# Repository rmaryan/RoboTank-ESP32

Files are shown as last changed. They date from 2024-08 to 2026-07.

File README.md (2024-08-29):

# RoboTank-ESP32

<table>
<tr>
    <td><H2>A source code and schematics for the ESP32-based robot with the 6-servos manipulator</H2></td>
<td>
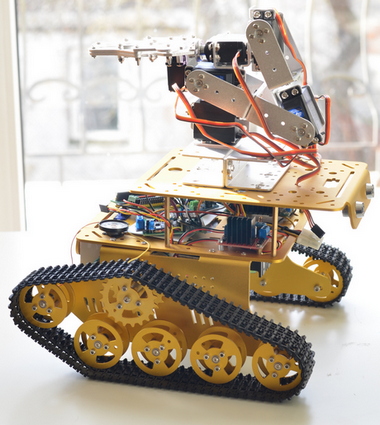
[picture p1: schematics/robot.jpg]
  
</td>
</tr>
</table>

## Contents
  * [Used Components](#used-components)
  * [ESP IDF Requirements](#esp-idf-requirements)
  * [Schematics](#schematics)
  * [Remote Control](#remote-control)
  * [Robot's Web Page and OTA](#robot-s-web-page-and-ota)
  * [On-board sounds](#on-board-sounds)
  * [3D Models](#3d-models)

## Used Components

  * [ESP32 DevBoard](https://www.banggood.com/ESP32-Development-Board-WiFibluetooth-Ultra-Low-Power-Consumption-Dual-Cores-ESP-32-ESP-32S-Board-p-1109512.html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)
  * [Geekcreit DT300 WIFI Double Decker Tank Chassis](https://www.banggood.com/DT300-WIFI-Double-Layer-Decker-Tracked-Model-Robot-Tank-DIY-Kit-Compatible-With-Arduino-UNO-R3-p-1079947.html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)
  * [L298N Dual H Bridge Motor Driver](https://www.banggood.com/Wholesale-L298N-Dual-H-Bridge-Stepper-Motor-Driver-Board-p-42826.html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)
  * [PCA9685 16-Channel 12-bit PWM Extender I2C](https://www.banggood.com/PCA9685-16-Channel-12-bit-PWM-Servo-Motor-Driver-I2C-Module-p-1170343.html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)
  * [6-DOF Robotic Arm](https://www.banggood.com/ROT2U-6DOF-Silver-Aluminium-Robot-Arm-Clamp-Claw-Mount-Kit-With-Servos-p-1118027.html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) - please note, we had to replace two of the original MG996R servos with stronger ones (see below)
  * [SPT Servo SPT5535LV-320 35KG 320°](https://www.banggood.com/SPT-Servo-SPT5535LV-320-35KG-Large-Torque-Metal-Gear-Digital-Servo-For-RC-Robot-RC-Robot-Arm-p-1577513.html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)
  * [SPT Servo SPT5525LV-320 25KG 320°](https://www.banggood.com/SPT-Servo-SPT5525LV-320-25KG-Digital-Servo-320-Metal-Gear-Large-Torque-Servo-For-RC-Robot-p-1383203.html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)
  * [Ultrasonic distance sensor HC-SR04 with the servo-mounting cradle](https://www.banggood.com/Wholesale-Geekcreit-Ultrasonic-Module-HC-SR04-Distance-Measuring-Ranging-Transducer-Sensor-DC-5V-2-450cm-p-40313.html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) 
  * [TowerPro SG90 Mini Gear Micro Servo 9g](http://www.banggood.com/TowerPro-SG90-Mini-Gear-Micro-Servo-9g-For-RC-Airplane-Helicopter-p-1009914.html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)
  * [Infrared Obstacle Detectors](https://www.banggood.com/5Pcs-Infrared-Obstacle-Avoidance-Sensor-Smart-Car-Robot-p-951032.html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) - 4x
  * [LED Lights caps](https://www.banggood.com/3mm5mm8mm10mm-Lightcup-5Pcs-For-RC-Car-LED-Lights-p-930752.html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)
  * [WS2812B SMD LED boards](https://www.banggood.com/10Pcs-DC-5V-3MM-x-10MM-WS2812B-SMD-LED-Board-Built-in-IC-WS2812-p-958213.html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)
  * [Logical Level Converter TXB0104 4-Bit](https://www.banggood.com/CJMCU-401-TXB0104-4-Bit-Bidirectional-Voltage-Level-Translator-Auto-Direction-Sensing-ESD-Protection-p-1149178.html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) - 2x
  * [Sound module WTV020-SD with Mini SD Card](https://www.banggood.com/WTV020-WTV020-SD-Mini-SD-Card-MP3-Sound-Module-For-PIC-WTV020-SD-16P-p-1540568.html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)
  * [LM386 Audio Amplifier](https://www.banggood.com/LM386-Module-20-Times-Gain-Audio-Amplifier-Module-With-Adjustable-Resistance-p-1111643.html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)
  * [Flysky 2.4G 6CH FS-iA6B Receiver](https://www.banggood.com/Flysky-2_4G-6CH-FS-iA6B-Receiver-PPM-Output-With-iBus-Port-p-978603.html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) - can be used with a RC transmitter like [FlySky FS-i6 2.4G 6CH](https://www.banggood.com/FlySky-FS-i6-2_4G-6CH-AFHDS-RC-Radion-Transmitter-With-FS-iA6B-Receiver-for-RC-FPV-Drone-p-983537.html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)
  * [DC-DC Step Down Power Converter](https://www.banggood.com/DC-DC-CC-CV-Buck-Converter-Board-Step-Down-Power-Supply-Module-7-32V-to-0_8-28V-12A-p-1245047.html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)
  * [Battery Management System 2S 7.4V 8A Peak Current 15A for 18650 Lithium Battery](https://www.banggood.com/2S-7_4V-8A-Peak-Current-15A-18650-Lithium-Battery-Protection-Board-With-Over-Charge-Protection-p-1259709.html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) - 2x
  * [18650 Li-Ion Elements](https://www.banggood.com/4Pcs-INR18650-30Q-3000mAh-20A-Discharge-Current-18650-Power-Battery-Unprotected-Button-Top-18650-Battery-For-Flashlights-E-Cig-Tools-p-10671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) - 4x, make sure you've got at least 20A rated max output. Arm servos can be very power-hungry.
  * [Geekcreit Green 0.28 Inch 2.6V-30V Mini Digital Voltmeter - 2x](https://www.banggood.com/5Pcs-Geekcreit-Green-0_28-Inch-2_6V-30V-Mini-Digital-Volt-Meter-Voltage-Tester-Voltmeter-p-980041.html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)

## ESP IDF Requirements

This project relies on the features introduced in ESP IDF version 4.1. Make sure you use at least this version.

## Schematics
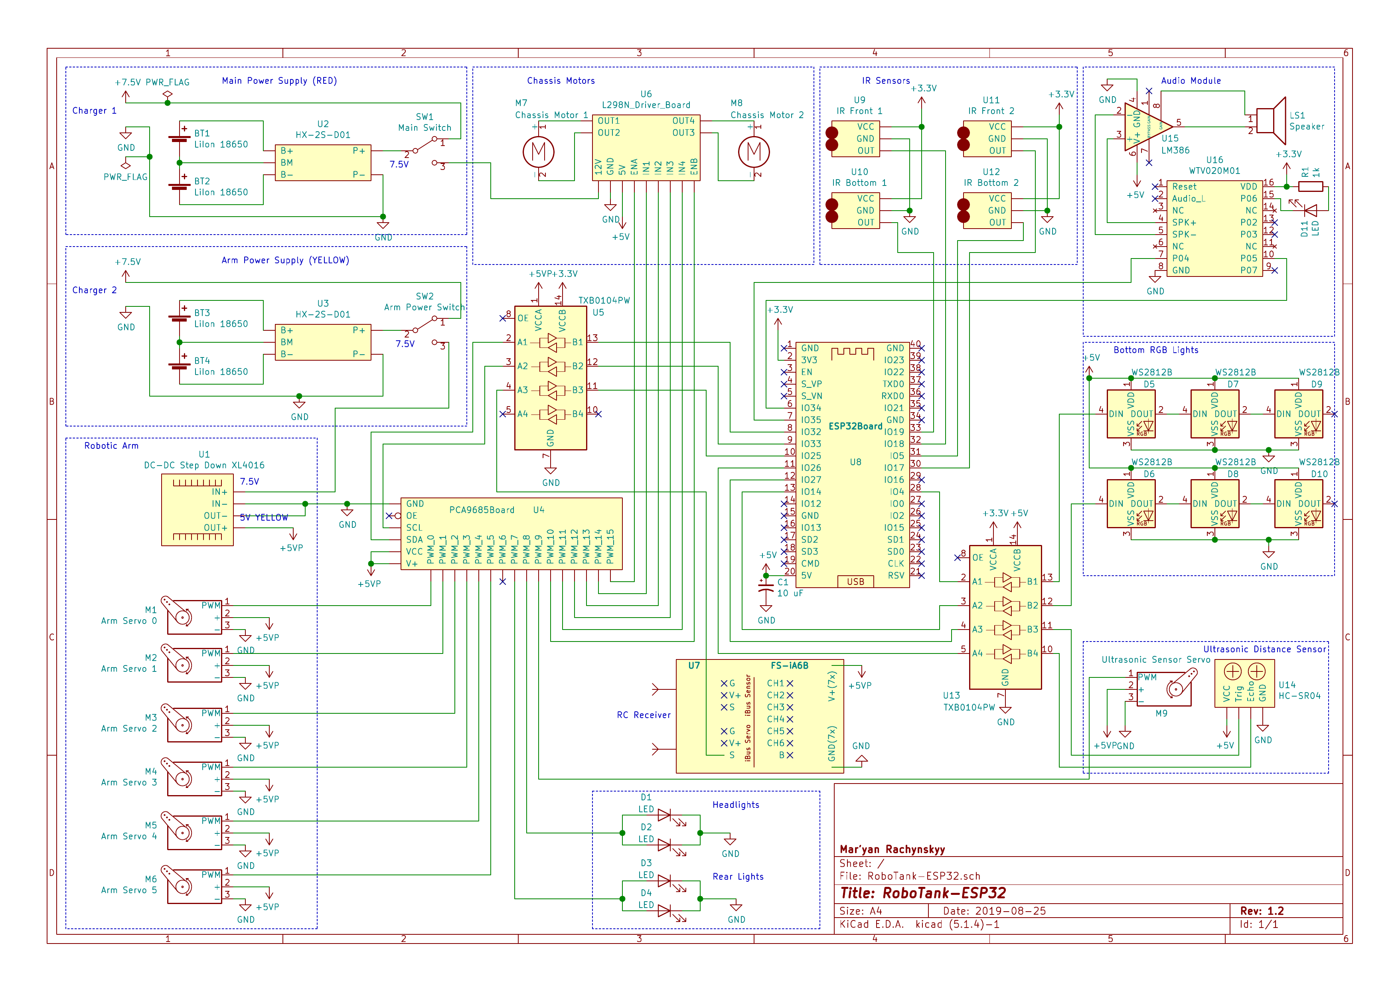
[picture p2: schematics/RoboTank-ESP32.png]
Schematics


## Remote Control

We use Flysky FS-i6 a 2.4GHz 6-channel transmitter which is absolutely sufficient for our case. 

The functionality was expanded with the alternative firmware version from this source: [https://github.com/qba667/FlySkyI6](https://github.com/qba667/FlySkyI6). The number of channels increased to 14 (we use 10 though). Also there are numerous functionality and ui improvements.

To access all channels at the robot's side, RC receiver is connected using iBus digital interface. Anyway it is more natural for the microcontroller-based projects, though require some processing power to read the messages stream and decode RC switches and gimbals positions.

### Flysky FS-i6 Layout

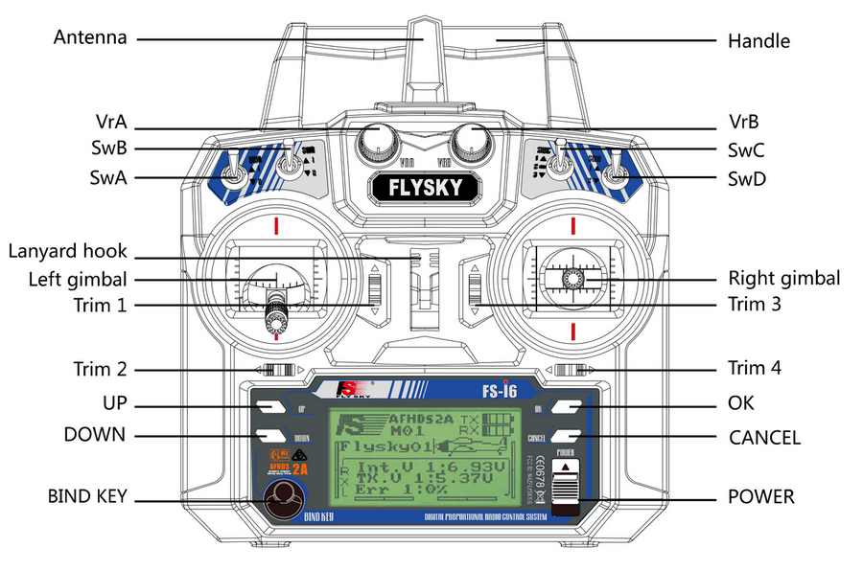
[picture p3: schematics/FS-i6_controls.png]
Flysky FS-i6 Controls


### RC Channels Mapping and Flow Chart

| RC Transmitter Switch | Channel # | Function |
| :--- | :---: | :--- |
| Left Gimbal | 3 and 4 | Controls the arm servos (depends on SWC position) |
| Right Gimbal | 1 and 2 | Controls the chassis motors |
| SWA | 5 | **Remote control activation** <br/>UP - Remote Control is active<br/>DOWN - Remote Control is inactive<br/>*After power on or reconnect, switch SWA down then up to activate RC. For the safety reasons all remote commands will be ignored until such initial activation sequence take place.* |
| SWB | 6 | **AI mode activation**<br/>UP - manual control mode<br/>DOWN - AI control mode (RC should still be activated first) |
| VRA | 7 | *nothing at the moment* |
| VRB | 8 | *nothing at the moment* |
| SWC | 9 | **Arm sevos pair selection**<br/> Selects which pair of servos are going to be controlled by the left gimbal (1=>top, 2=>middle, 3=>bottom) |
| SWD | 10 | **Lights Toggle**<br/>UP - all lights ON<br/>DOWN - all lights OFF |

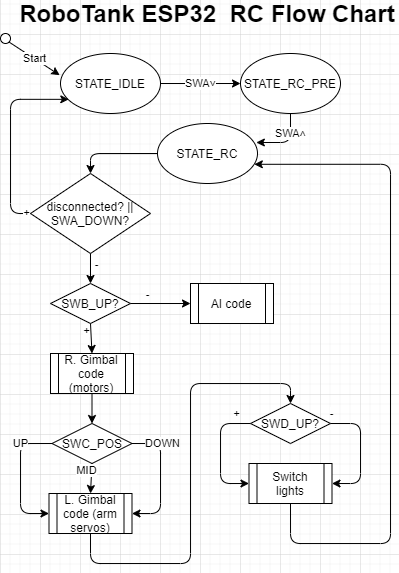
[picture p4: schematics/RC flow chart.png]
RC Flow Chart


## Robot's Web Page and OTA

Right after booting, the robot tries to connect to the local WiFi network. Connection parameters can be specified in "OTA WiFi Configuration" in make menuconfig.  

Having a connection started, robot launches own Web Server. You can find the IP address of the robot in your WiFi router settings pages (making it static can be a good idea). 

Direct your web browser to the robot's IP address and a home page will be shown. You can upload new firmware updates there (so you don't need to connect your robot with the USB wire any more). Also you can see the log messges output right on the web page (this feature will work if LOG_USE_WEB_FRONTEND is defined in RoboTank-ESP32.cpp). 

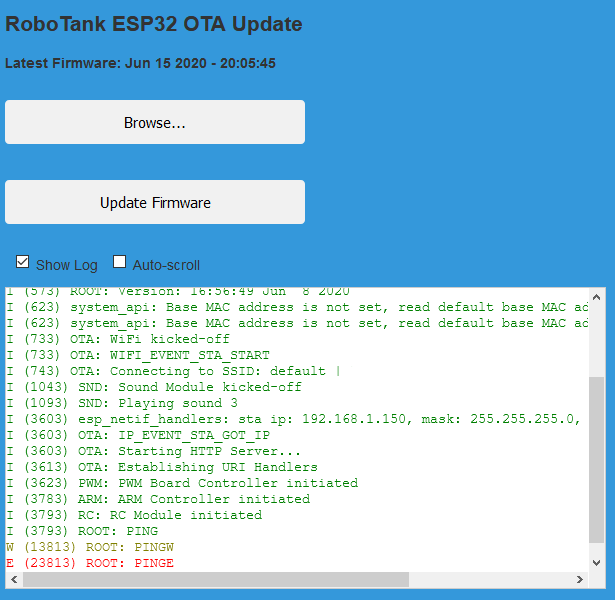
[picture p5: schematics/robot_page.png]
Schematics


## On-board sounds

Place the files from sdcard folder to the root of the sound module SD card.

Tracks are the following:
  * 0000.AD4 - Thinking
  * 0001.AD4 - Working
  * 0002.AD4 - Talking
  * 0003.AD4 - Hello
  * 0004.AD4 - Scared
  * 0005.AD4 - Be careful
  * 0006.AD4 - Vivaldi - Winter

Files were converted from the original MP3's as described here: https://www.buildcircuit.com/how-to-convert-mp3-and-wav-files-to-ad4-format-wtv020sd-tutorial/

## 3D Models

Some of the parts were 3D-printed. Corresponding FreeCAD and STL files are provided in the [schematics/3D Models](schematics/3D%20Models) folder.

  * RC Antenna cradle
  * IR distance sensors consoles
  * Backside voltmeters cradles
  
# Liked some of my work?

<a href="https://www.buymeacoffee.com/maryanR" target="_blank">Buy Me A Coffee</a>

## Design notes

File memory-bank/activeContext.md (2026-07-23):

# Active Context: RoboTank-ESP32

## Current Work Focus
Initial memory bank creation for the project. The codebase is a well-structured ESP32 firmware application built with PlatformIO and ESP-IDF framework, managing multiple robotic subsystems concurrently via FreeRTOS tasks.

## Recent Changes
No recent changes documented yet - this is the first session documenting this repository (commit: `cdf3718`).

## Next Steps
- Review all source files in detail to understand current implementation state
- Validate RC controller PWM signal processing logic

## Active Decisions and Considerations
- Project uses `include/` for headers and `src/` for implementations consistently
- Pin configuration is centralized in `pin_mapping.h` header - reference this file before any hardware-related changes
- FreeRTOS tasks are used extensively (AITask, RCControllerTask) with separate task files
- PlatformIO platform (`platformio.ini`) drives the build system rather than raw ESP-IDF Makefiles (beware - project uses pioarduino fork and VS Code plugin)

## Important Patterns and Preferences
- Each subsystem has both a header (.h) implementation (.cpp) pair in `include/` and `src/` respectively
- Utility functions are centralized in `RoboTankUtils.cpp`
- Per-module logging via `rtank_esp_log.h` for consistent log output

## Learnings and Project Insights
- The project includes schematics for mechanical design (`3D Models/`) and circuit diagrams (`flow chart.drawio`, `.png`) - useful reference before hardware-related modifications
- SD card directory contains `.AD4` sound files (WTV020SD16P format) for playback via SoundModuleController at track IDs 1-512

<!-- MEMORY BANK INITIALIZED -->

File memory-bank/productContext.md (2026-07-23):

# Product Context: RoboTank-ESP32

## Purpose
RoboTank-ESP32 serves as a fully programmable, WiFi-enabled robotic tank platform designed for educational purposes and hobbyist experimentation with robotics, embedded systems, and IoT concepts.

## Problems Solved
- **Complex hardware integration**: Provides pre-built, tested drivers for common robot components (motors, servos, sensors) so users can focus on application logic
- **Wireless control convenience**: Enables RC-style control combined with WiFi-based OTA updates and web interface access
- **Development workflow simplification**: PlatformIO + ESP-IDF setup eliminates manual SDK configuration

## How It Works
The system operates through multiple FreeRTOS tasks running on the ESP32:
1. **RCControllerTask** reads PWM signals from an FS-i6 transmitter receiver and maps channels to robot commands
2. **AITask** handles autonomous/remote logic processing based on RC input and sensor data
3. **Component controllers** (ArmController, MotorsL298NDriver, LEDsMT, SensorsController, etc.) manage individual hardware subsystems concurrently
4. **BufLogger** handles logging: intercepts ESP-IDF log output into ring buffer → serves via HTTP to web page + serial port
5. **OTAManager** handles firmware updates without physical connection

## User Experience Goals
- Plug-and-play setup with PlatformIO upload via USB or OTA
- Immediate feedback through LEDs, sounds, and motor response
- Intuitive RC control mapping for both manual operation and programmed sequences
- Reliable sensor readings and actuator responses in real-time

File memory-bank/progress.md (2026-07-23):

# Progress: RoboTank-ESP32

## What Works
Based on existing codebase analysis, the following subsystems appear implemented:
- RC Controller PWM signal decoding (FS-i6 protocol) for channel reading and command mapping
- Motor control via L298N driver interface with directional/speed commands from RC input or AI task logic
- Servo-based robotic arm position management through ArmController
- RMT-driven RGB LED strip effects managed by LEDsMT controller
- Sensor data aggregation pipeline in SensorsController for real-time state monitoring and feedback to tasks
- Audio playback system integration via SoundModuleController (likely WAV/MP3 module communication)
- OTA firmware update capability with OTAManager handling WiFi-based upload workflow without serial reconnection
- Pin mapping validation against physical build wiring (`include/pin_mapping.h`) verified with actual hardware connections shown in schematics
- RC controller signal processing accuracy for FS-i6 receiver (PPM protocol) tested on real hardware successfully
- Sensor calibration values and threshold configurations tuned per installed sensors, all thresholds working correctly

## What's Left to Build / Improve
### General
- Power management integration between LightsController sleep/wake cycle, OTAManager power considerations during OTA window, and overall current draw optimization
- Web interface content in `src/webcontent/` directory - endpoint handlers for WiFi AP/client mode operation not yet visible from file structure alone

### AI Mode Implementation (TODO)
- `AITask::processTickAI()` contains only a `ArmController::parkArm()` call — the method body is marked as TODO
  - **Option A**: Implement basic autonomous mode (obstacle avoidance + patrolling behavior)
  - **Option B**: Rename to `manualMode()` or `rcControlTick()` if AI autonomy is out of scope
- Current state at `src/AITask.cpp`: empty stub with single park call as placeholder

### Hard-coded Timeouts and Magic Numbers
- `OTAManager.cpp` line ~290: index calculation `(body_start_p - ota_buff)` without explicit intermediate variables — hard to read and debug
- `SensorsController.cpp` line ~145: `rmt_receive()` + `xQueueReceive()` in `while(1)` loop with 1000ms timeout
  - **Risk**: If US sensor is not connected or unstable, this blocks the task for 1+ second
  - **Recommendation**: Use non-blocking RMT callbacks or shorter timeouts with periodic polling

### Insufficient Error Handling on init() Calls
- Multiple modules call `init()` without checking ESP-IDF return codes (`esp_err_t`):
  - `MotorL298NDriver::init()` — what if I2C bus is unavailable?
  - `ArmController::init()` — was PCA9685 initialized successfully?
  - **Recommendation**: Add error checks on all ESP-IDF driver initialization calls; log failures and return status codes

### Pin Configuration Refactoring
- `include/pin_mapping.h` contains all hardware connections as hard-coded macros
- **Recommendation**: Move configurable pins to:
  - `sdkconfig` or NVS for pins that may vary between project builds
  - A `pin_config_t` struct with runtime validation

### OTA Safety Improvements
- Current code lacks firmware integrity verification:
  - No CRC/hash check of uploaded firmware — corrupted file can brick the device
  - No `content_length` validation before writing
- **Recommendation**: Add HMAC or XOR checksum verification before `esp_ota_end()`

### Persistent Storage for Configuration Data (NVS)
- WiFi credentials are stored in ESP-IDF WIFI_STORAGE (Flash), but the following are NOT persisted:
  - Servo calibration data (`SERVO_CALIBRATION_MODE`)
  - Last device state / events for debugging purposes
- **Recommendation**: Use NVS to store calibration tables, last known state, and error logs

## Current Status
**Version**: Early-stage firmware (commit `cdf3718`)
**State**: Core modules implemented, integration testing needed per subsystem combination
**Branch**: main (default)

## Known Issues
Not documented in codebase history yet. To be updated as bugs are discovered during hardware testing and field trials.

## Evolution of Project Decisions
Initial memory bank created at commit `cdf3718`. Key architectural decisions to revisit as hardware iterations occur:
- L298N vs MOSFET motor drivers (power efficiency tradeoffs)
- RMT peripheral for LEDs vs DMA SPI (pixel timing precision requirements depend on LED chip type WS2812B etc.)
- FS-i6 RC receiver protocol selection determining `RCControllerTask` parsing approach

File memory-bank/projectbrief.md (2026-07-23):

# Project Brief: RoboTank-ESP32

## Overview
RoboTank-ESP32 is an ESP32-based robotic tank project featuring advanced control systems including arm manipulation, sensor integration, wireless communication, and SD card logging.

## Core Requirements
- Remote control via RC transmitter (FS-i6) with PWM signal decoding
- Robotic arm control with multiple degrees of freedom
- Real-time sensor monitoring and feedback
- LED strip effects for visual indication
- Audio playback module for alerts/announcements
- Over-the-Air (OTA) firmware updates
- Web-based interface capabilities for triggering OTA and reviewing logs

## Key Features
- Multi-module architecture with separated concerns
- Non-blocking task management via FreeRTOS tasks
- Power-efficient design with sleep/wake support
- Modular component drivers for reusable hardware abstraction

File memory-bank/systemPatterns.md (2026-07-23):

# System Patterns: RoboTank-ESP32

## Architecture Overview
The system follows a **Modular Task-Based** architecture where each major subsystem operates as an independent module with clear separation of concerns. The main entry point is `src/Robo-tank-ESP32.cpp` which initializes all components and starts FreeRTOS tasks.

## Key Technical Decisions

### FreeRTOS Task Model
- Multiple concurrent tasks communicate via queues, semaphores, or shared state
- **AITask.h/cpp** - Central AI/logic coordination task handling high-level decisions
- **RCControllerTask.h/cpp** - Dedicated RC signal processing task running independently

### Hardware Abstraction Pattern
Each peripheral has its own controller class:
- `ArmController` - Servo-based robotic arm manipulation
- `MotorL298NDriver` - DC motor control via L298N H-bridge module
- `LEDRMT` - RGB LED strip driver using RMT peripheral
- `LightsController` - Tank lighting system management
- `SensorsController` - Multi-sensor data aggregation
- `SoundModuleController` - WTV020SD16P sound board controller for .AD4 track playback (files stored on SD card)
- `PWMBoardController` - PWM signal generation/board-level output

### Logging Architecture
- **BufLogger** - Intercepts esp-log framework via ring buffer, collects messages and redirects them to alternative receivers (serial port + web page). On overflow, oldest messages are dropped. Does NOT write to SD card.
- **rtank_esp_log.h/cpp** - Module-specific log wrapper using ESP-IDF log facility

## Component Relationships
```
                     +------------------+
                     |   main (Entry)   |
                     +--------+---------+
                              |
             +---------------+---------------+
             |               |               |
      +------v-----+  +------v------+ +----v-------+
      | AITask     |  | RCController| | OTAManager |
      +------------+  +-------------+ +------------+
             |               
     +-------v---------------+--------+       
     |         Shared State / API      |     
     +-------------------------------+        
                             |                
            +--------------+--+--+-----------+ 
            |              |       |          |      
   +------v------+ +-----v----+ +-v---------+-+----------+
   |ArmController|  | Motors   ||Sensors    ||SoundModule|
   +-------------+  +----------+ +----------++-+---------+
            |                             |           |     
   +-------v--------+             +------v------+     v      
   |PWMBoardCtrl/Li|          +-WebServer----->|  .AD4 Files
   +----------------+          | (BufLogger)    |     on SD    
   +------------------+        +----------------+ 
```

## Sound System Architecture
- **SoundModuleController** manages WTV020SD16P sound module via parallel port interface
- Sounds stored as `.AD4` files on SD card (track IDs 1-512)
- Triggered by other modules during specific events (e.g., AI decisions, sensor alerts)

## Design Patterns in Use
- **Controller Pattern**: Each hardware subsystem has a dedicated controller class
- **Observer-like communication**: Shared state updates trigger downstream reactions
- **Singleton-style modules**: Controller instances typically created once at initialization with global/static access patterns

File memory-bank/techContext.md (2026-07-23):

# Tech Context: RoboTank-ESP32

## Technologies Used
- **Microcontroller**: ESP32 (dual-core Xtensa LX6)
- **Framework**: ESP-IDF (Espressif IoT Development Framework)
- **Build System**: PlatformIO with CMake (pioarduino fork)
- **RTOS**: FreeRTOS (bundled with ESP-IDF)
- **Language**: C/C++

## Development Environment Setup
- IDE: VS Code with pioarduino extension
- Configuration file: `platformio.ini` in project root
- Upload methods: USB serial or OTA (`OTAManager`)

## Dependencies & Libraries
Dependencies are declared in `platformio.ini`. Key ones likely include:
- ESP-IDF core (WiFi, SPIFFS/LittleFS)
- RMT driver for LED control
- Servo/PWM drivers for arm and motors
- SD/MMC library for card storage
- FS-i6 RC receiver signal decoding (PWM/GCS protocol parsing)

## Technical Constraints
- **Memory**: ESP32 SRAM (~520KB internal), PSRAM if equipped
- **Power**: Battery-powered, requires sleep/wake support (`LightsController` and `OTAManager`) for power management
- **Pin mapping**: Centralized in `include/pin_mapping.h` - all hardware references must align here
- **WiFi antenna**: Internal PCB trace on ESP32-WROOM; RF considerations near antenna area

## Tool Usage Patterns
- PlatformIO CLI (`pio run`, `pio upload`, ` pio device monitor`) for build/deploy/debug cycle - beware of the pioarduino specifics
- CMakeLists.txt in both root and `src/` directories (PlatformIO handles this automatically)

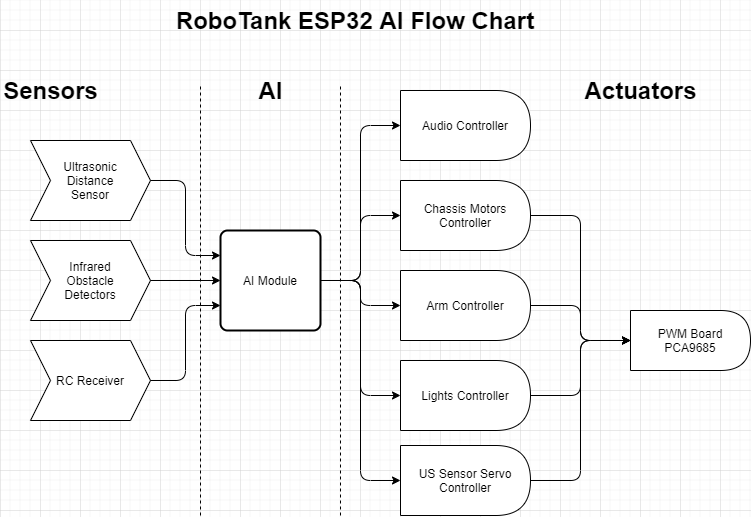
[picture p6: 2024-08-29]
schematics/flow chart.png

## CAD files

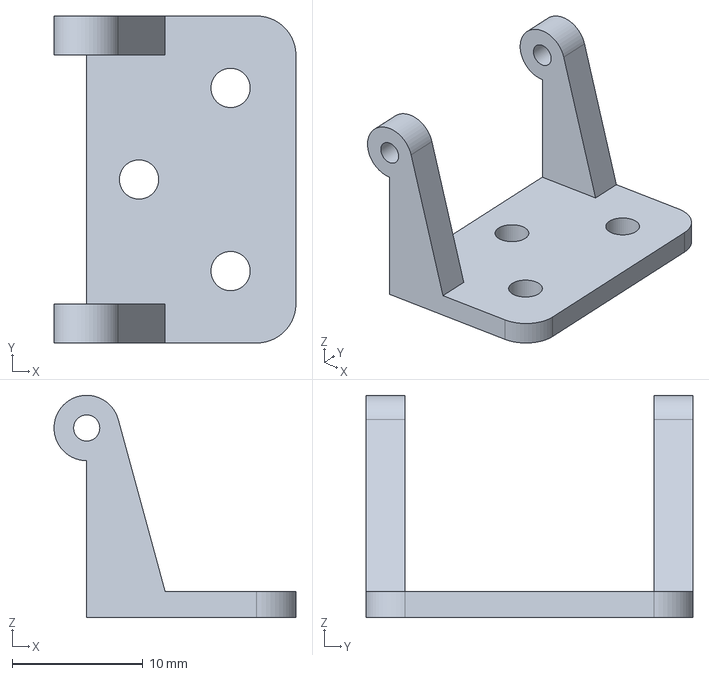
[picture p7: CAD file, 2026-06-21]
schematics/3D Models/FPVCameraHolder.FCStd
18.5 x 25.0 x 17.0 mm

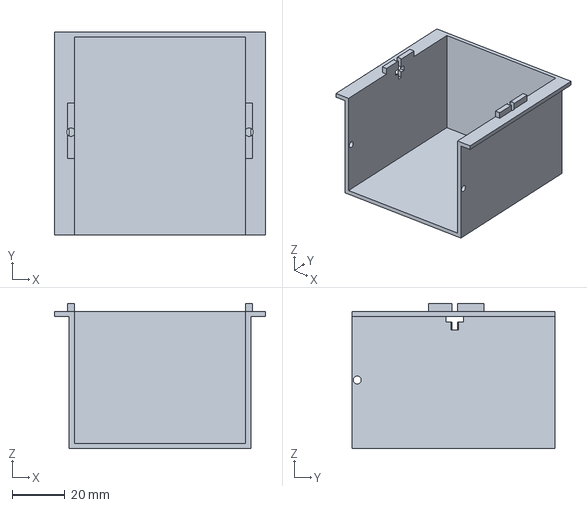
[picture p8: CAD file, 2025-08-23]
schematics/3D Models/BatHolder.FCStd
80.0 x 77.0 x 55.0 mm

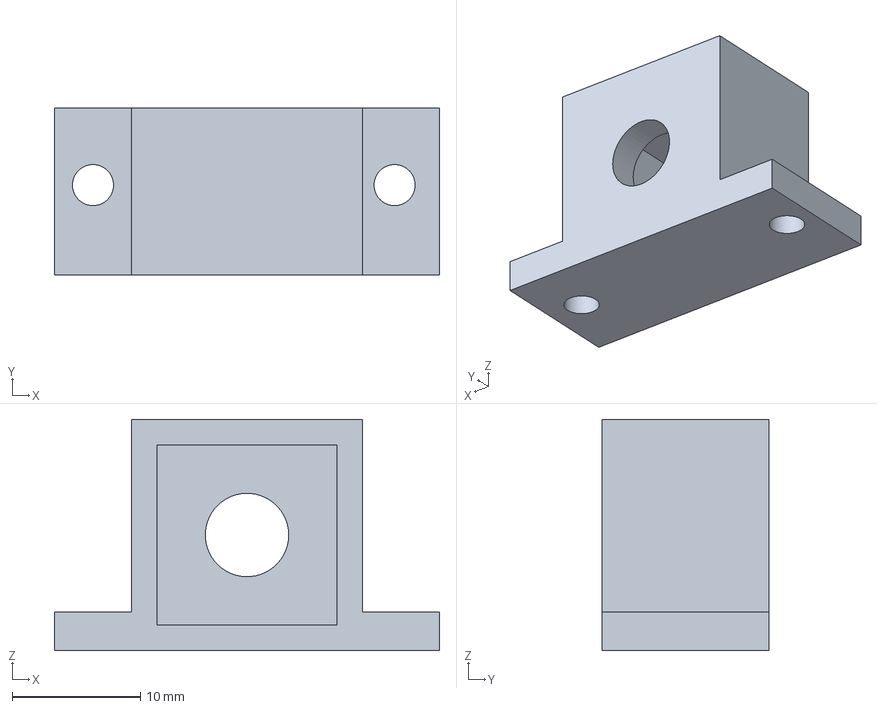
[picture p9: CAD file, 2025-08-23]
schematics/3D Models/SwitchHolder.FCStd
30.0 x 13.0 x 18.0 mm

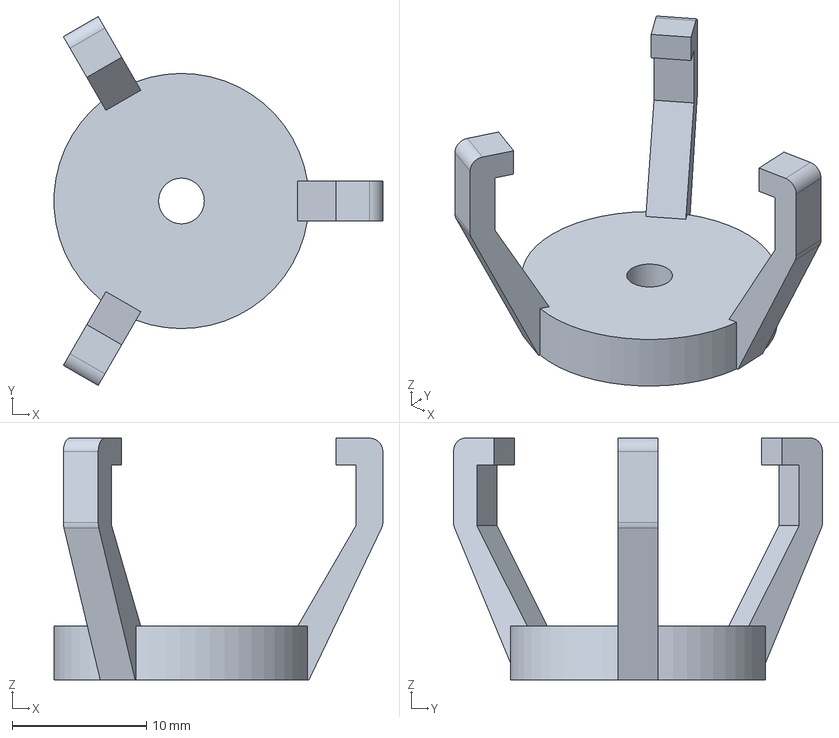
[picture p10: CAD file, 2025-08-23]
schematics/3D Models/BeeperHolder.FCStd
24.5 x 27.5 x 18.0 mm

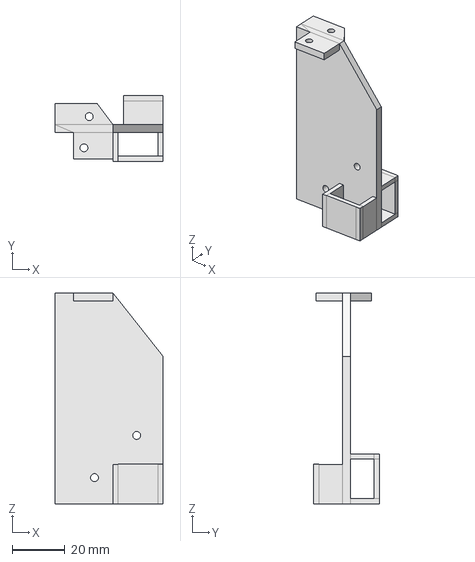
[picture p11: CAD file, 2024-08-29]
schematics/3D Models/sensors_console.FCStd
41.0 x 25.0 x 80.0 mm

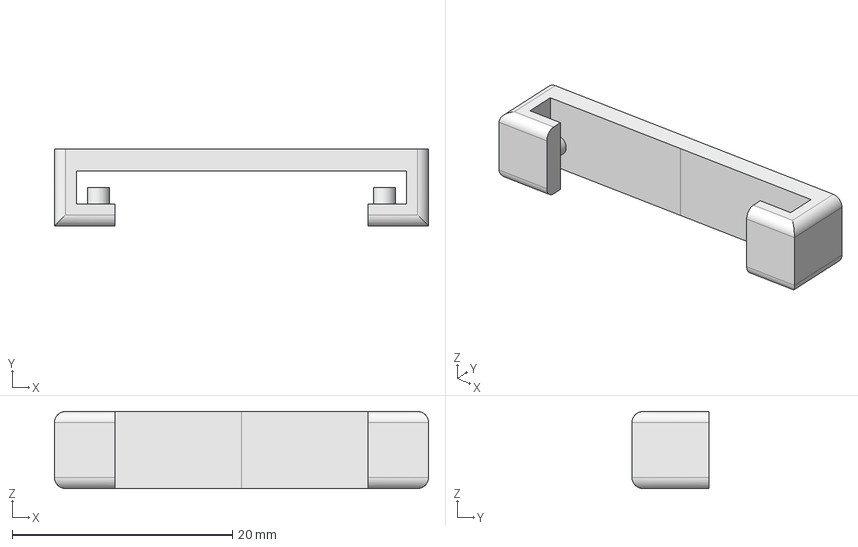
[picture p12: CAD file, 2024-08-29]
schematics/3D Models/voltmeter_cradle.FCStd
34.0 x 7.00 x 7.00 mm

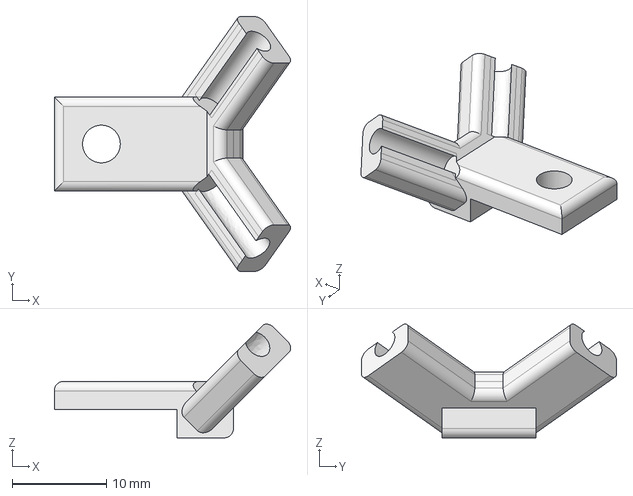
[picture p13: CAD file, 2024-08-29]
schematics/3D Models/antenna_cradle.FCStd
25.1 x 27.0 x 12.1 mm

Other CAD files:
schematics/3D Models/BatHolder.3mf
schematics/3D Models/BeeperHolder.3mf
schematics/3D Models/FPVCameraHolder.3mf
schematics/3D Models/SwitchHolder.3mf
schematics/3D Models/sensors_console.3mf
schematics/3D Models/sensors_console.stl
schematics/3D Models/voltmeter_cradle.stl

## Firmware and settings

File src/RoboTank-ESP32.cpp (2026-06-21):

/*
 *  Tank robot with sensors and manipulators built on ESP32 microcontroller.
 *
 *  THE ENTRY POINT
 *
 *  Minimum ESP-IDF version required: 4.0
 *
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
 */

#include "rtank_esp_log.h"
#include "freertos/FreeRTOS.h"
#include "freertos/task.h"
#include "OTAManager.h"
#include "PWMBoardController.h"
#include "MotorL298NDriver.h"
#include "SoundModuleController.h"
#include "ArmController.h"
#include "LightsController.h"
#include "SensorsController.h"
#include "RCControllerTask.h"
#include "AITask.h"
#include "RoboTankUtils.h"

#ifdef LOG_USE_WEB_FRONTEND
#include "BufLogger.h"
#endif

static const char* LOG_TAG = LOG_TAG_ROOT;

extern "C" {
void app_main();
}

void app_main()
{
	// Initialize the logging subsystem
	// It allows selecting different log levels for each module
	rtank_esp_log_init();

	// Initialize the web front-end logger
#ifdef LOG_USE_WEB_FRONTEND
	BufLogger::init();
#endif

	ESP_LOGI(LOG_TAG, "Starting the launch sequence...");
	ESP_LOGI(LOG_TAG, "Version: %s %s", __TIME__, __DATE__);

	// Initializing the OTA and web server subsystem
	OTAManager::init();

	// Hello Sound!
	SoundModuleController::init();


	// PWM Board
	PWMBoardController::init();

	// Stop all motors
	MotorL298NDriver::init();

	// Arm Controller
	ArmController::init();
	// This is the arm servos calibration hook.
	// If you uncomment SERVO_CALIBRATION_MODE definition in ArmController.h - the main execution thread is highjacked
	// Connect to the robot in serial console and send servo position commands as requested. This way you can define edge
	// and parking positions for the servos.
#ifdef SERVO_CALIBRATION_MODE
	ArmController::servoCalibration();
	// Nothing is executed beyond this step
#endif

	// Lights controller
	LightsController::init();

	// IR and Ultrasonic Sensors
	SensorsController::init();

	//RC Controller
	RCControllerTask::init();

	//Launch of the AI. Wait 1 second for other modules to settle.
	delay_ms(1000);
	AITask::init();

}

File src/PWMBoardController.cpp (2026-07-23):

/*
 * PWMBoardController.cpp
 *
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
 */

#include "PWMBoardController.h"

#include <math.h>

#include "driver/i2c.h"
#include "esp_check.h"
#include "rtank_esp_log.h"
#include "pin_mapping.h"

// Board-specific definitions
#define I2C_CLK_SPEED 100000		  /* I2C clock speed in Hz */
#define PCA9685_I2C_ADDRESS 0x40	  /* Default PCA9685 I2C Slave Address */
#define FREQUENCY_OSCILLATOR 25000000 /* Int. osc. frequency in datasheet */
#define PCA9685_PRESCALE 0xFE		  /* Prescaler for PWM output frequency */
#define PCA9685_MODE1 0x00			  /* Mode Register 1 */
#define MODE1_RESTART 0x80			  /* Restart enabled */
#define MODE1_SLEEP 0x10			  /* Low power mode. Oscillator off */
#define MODE1_AI 0x20				  /* Auto-Increment enabled */
#define PCA9685_PRESCALE_MIN 3		  /* minimum prescale value */
#define PCA9685_PRESCALE_MAX 255	  /* maximum prescale value */
#define ACK_CHECK_EN 0x1			  /* Check for ACK on I2C bus*/
#define PCA9685_LED0_ON_L 0x06		  /* LED0 on tick, low byte*/

// We hardcode 50 Hz - this is what works for the analog servos
#define SERVOFREQ 50

static const char *LOG_TAG = LOG_TAG_PWM;

SemaphoreHandle_t PWMBoardController::xPWMSemaphore;

void PWMBoardController::init()
{
	// set up the I2C interface
	ESP_LOGI(LOG_TAG, "Initializing the PWM Board Controller...");

	i2c_config_t conf = {};
	conf.mode = I2C_MODE_MASTER;
	conf.sda_io_num = PIN_ESP32_PWM_SDA;
	conf.scl_io_num = PIN_ESP32_PWM_SCL;
	conf.sda_pullup_en = GPIO_PULLUP_ENABLE;
	conf.scl_pullup_en = GPIO_PULLUP_ENABLE;

	conf.master.clk_speed = I2C_CLK_SPEED; // 100 kHz
	ESP_ERROR_CHECK(i2c_param_config(I2C_NUM_0, &conf));
	ESP_ERROR_CHECK(i2c_driver_install(I2C_NUM_0, conf.mode, 0, 0, 0));

	// reset the PWM board
	ESP_ERROR_CHECK(sendPWMData(PCA9685_MODE1, MODE1_RESTART));

	// set up the desired PWM frequency
	float prescaleval = ((FREQUENCY_OSCILLATOR / (SERVOFREQ * 4096.0)) + 0.5) - 1;
	if (prescaleval < PCA9685_PRESCALE_MIN)
		prescaleval = PCA9685_PRESCALE_MIN;
	if (prescaleval > PCA9685_PRESCALE_MAX)
		prescaleval = PCA9685_PRESCALE_MAX;
	uint8_t prescale = round(prescaleval);

	uint8_t oldmode = receivePWMData(PCA9685_MODE1);
	uint8_t newmode = (oldmode & ~MODE1_RESTART) | MODE1_SLEEP; // sleep
	ESP_ERROR_CHECK(sendPWMData(PCA9685_MODE1, newmode));		// go to sleep
	ESP_ERROR_CHECK(sendPWMData(PCA9685_PRESCALE, prescale));	// set the prescaler
	ESP_ERROR_CHECK(sendPWMData(PCA9685_MODE1, oldmode));
	vTaskDelay(5 / portTICK_PERIOD_MS);
	ESP_ERROR_CHECK(sendPWMData(PCA9685_MODE1, oldmode | MODE1_RESTART | MODE1_AI));
	vTaskDelay(10 / portTICK_PERIOD_MS);

	// Create the access safeguard mutex
	xPWMSemaphore = xSemaphoreCreateMutex();
	if (xPWMSemaphore == NULL)
	{
		ESP_LOGE(LOG_TAG, "Semaphore creation failed");
	}

	ESP_LOGI(LOG_TAG, "PWM Board Controller initiated");
}

esp_err_t PWMBoardController::sendPWMData(uint8_t addr, uint8_t data)
{
	esp_err_t error_code;
	i2c_cmd_handle_t cmd = i2c_cmd_link_create();
	i2c_master_start(cmd);
	i2c_master_write_byte(cmd, (PCA9685_I2C_ADDRESS << 1) | I2C_MASTER_WRITE, ACK_CHECK_EN);
	i2c_master_write_byte(cmd, addr, ACK_CHECK_EN);
	i2c_master_write_byte(cmd, data, ACK_CHECK_EN); // potentially for the registers should be NACK_VAL
	i2c_master_stop(cmd);
	error_code = i2c_master_cmd_begin(I2C_NUM_0, cmd, 100 / portTICK_PERIOD_MS);
	i2c_cmd_link_delete(cmd);
	return error_code;
}

bool PWMBoardController::setPWM(uint8_t num, uint16_t on, uint16_t off)
{
	if (xSemaphoreTake(xPWMSemaphore, (TickType_t)400) != pdTRUE)
	{
		ESP_LOGE(LOG_TAG, "Semaphore timeout. PWM command was lost.");
		return false;
	}

	i2c_cmd_handle_t cmd = i2c_cmd_link_create();
	if (cmd == NULL)
	{
		xSemaphoreGive(xPWMSemaphore);
		return false;
	}
	esp_err_t ret = ESP_OK;
	uint8_t data[5] = {
		(uint8_t)(PCA9685_LED0_ON_L + 4 * num),
		(uint8_t)(on & 0xFF),
		(uint8_t)((on >> 8) & 0xFF),
		(uint8_t)(off & 0xFF),
		(uint8_t)((off >> 8) & 0xFF)};

	ESP_GOTO_ON_ERROR(i2c_master_start(cmd), err, LOG_TAG, "Failed to set PWM on channel %d: error code 0x%x", num, ret);
	ESP_GOTO_ON_ERROR(i2c_master_write_byte(cmd, (PCA9685_I2C_ADDRESS << 1) | I2C_MASTER_WRITE, ACK_CHECK_EN), err, LOG_TAG, "Failed to set PWM on channel %d: error code 0x%x", num, ret);
	ESP_GOTO_ON_ERROR(i2c_master_write(cmd, data, sizeof(data), ACK_CHECK_EN), err, LOG_TAG, "Failed to set PWM on channel %d: error code 0x%x", num, ret);
	ESP_GOTO_ON_ERROR(i2c_master_stop(cmd), err, LOG_TAG, "Failed to set PWM on channel %d: error code 0x%x", num, ret);
	ESP_GOTO_ON_ERROR(i2c_master_cmd_begin(I2C_NUM_0, cmd, 10 / portTICK_PERIOD_MS), err, LOG_TAG, "Failed to set PWM on channel %d: error code 0x%x", num, ret);

err:
	i2c_cmd_link_delete(cmd);
	xSemaphoreGive(xPWMSemaphore);

	return (ret == ESP_OK);
}
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

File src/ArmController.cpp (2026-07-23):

/*
 * ArmController.cpp
 *
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
 */

#include <stdio.h>
#include <stdlib.h>
#include <math.h>
#include "rtank_esp_log.h"
#include "ArmController.h"
#include "PWMBoardController.h"
#include "RoboTankUtils.h"

const uint8_t ArmController::SERVO_PWM_PORTS[SERVOS_COUNT] = {
		PIN_PWM_ARM_SERVO0,
		PIN_PWM_ARM_SERVO1,
		PIN_PWM_ARM_SERVO2,
		PIN_PWM_ARM_SERVO3,
		PIN_PWM_ARM_SERVO4,
		PIN_PWM_ARM_SERVO5
};

const uint8_t ArmController::SERVO_MIN_DEG[SERVOS_COUNT] = 	 {0,   15,  10,  30,  10,  45};
const uint8_t ArmController::SERVO_MAX_DEG[SERVOS_COUNT] =   {178, 165, 180, 170, 170, 85};
const uint8_t ArmController::SERVO_PARK_DEG[SERVOS_COUNT] =  {85,  20,  10,  50,  90,  71}; // arm parking positions. Set 255 to skip

uint16_t ArmController::servo_current_position[SERVOS_COUNT] = {};
int16_t  ArmController::servo_current_speed[SERVOS_COUNT] = {};
uint16_t ArmController::servo_target_position[SERVOS_COUNT] =  {};
uint8_t ArmController::servo_target_positionDEG[SERVOS_COUNT] =  {};

#define SERVO_TIMER_TASK_NAME "SERVO TIMER"
TimerHandle_t ArmController::xServoUpdateTimerHandle;

static const char* LOG_TAG = LOG_TAG_ARM;

void ArmController::init() {
	// Make sure the arm is initialized in the parked position
	// Be careful about what you have in your SERVO_PARK_DEG
	// or uninitialized arm can damage lots of stuff around the robot
	parkArm();
	for(int8_t i = (SERVOS_COUNT-1); i>=0; i--) {
		servo_current_position[i] = servo_target_position[i];
		PWMBoardController::setPWM(SERVO_PWM_PORTS[i], 0, servo_current_position[i]);
	}

	// start the arm moving timer task
	// we use it to move smoothly all servos of the arm simultaneously
	xServoUpdateTimerHandle = xTimerCreate(
			SERVO_TIMER_TASK_NAME,
			pdMS_TO_TICKS(SERVO_STEP_DURATION), /* period/time */
			pdTRUE, /* auto reload */
			(void*)0, /* timer ID */
			servoTimerCallback); /* callback */

	if (xServoUpdateTimerHandle!=NULL) {
		if(xTimerStart(xServoUpdateTimerHandle, 0) == pdPASS ) {
			ESP_LOGI(LOG_TAG, "ARM Controller initiated");
		} else {
			ESP_LOGE(LOG_TAG, "ARM Controller Timer start failed");
		}
	} else {
		ESP_LOGE(LOG_TAG, "ARM Controller Timer creation failed");
	}
}

void ArmController::turnServo(uint8_t servoID, int16_t turningAngleDEG) {	
	if((servoID < SERVOS_COUNT) && (turningAngleDEG != 0)) {
		ESP_LOGI(LOG_TAG, "Turning servo %d by %d degrees", servoID, turningAngleDEG);
		int16_t desiredPositionDEG = servo_target_positionDEG[servoID] + turningAngleDEG;
		if(desiredPositionDEG< SERVO_MIN_DEG[servoID])
			desiredPositionDEG = SERVO_MIN_DEG[servoID];
		else
			if(desiredPositionDEG > SERVO_MAX_DEG[servoID])
				desiredPositionDEG = SERVO_MAX_DEG[servoID];

		setServo(servoID, desiredPositionDEG);
	}
}

void ArmController::parkArm() {
	for(int8_t i = (SERVOS_COUNT-1); i>=0; i--) {
		if (SERVO_PARK_DEG[i] != 255) {
            setServo(i, SERVO_PARK_DEG[i]);
        }
	}
}

void ArmController::setServo(uint8_t servoID, uint8_t servoPositionDEG) {
	// Check the parameters validity not to harm innocent PWM lines
	if(servoID < SERVOS_COUNT) {
		if((servoPositionDEG>= SERVO_MIN_DEG[servoID]) &&
				(servoPositionDEG<= SERVO_MAX_DEG[servoID])) {
			servo_target_positionDEG[servoID] = servoPositionDEG;
			servo_target_position[servoID] = map(servoPositionDEG, 0, 180, SERVOMIN_PULSE, SERVOMAX_PULSE);
		}
	}
}

void ArmController::servoTimerCallback(TimerHandle_t pxTimer) {
	for(int servoID = 0; servoID<SERVOS_COUNT; servoID++) {
		if(servo_current_position[servoID] == servo_target_position[servoID]) {
			// nothing to do for this servo
			continue;
		}

		// detect the desired rotation direction
		bool positiveDirection = servo_current_position[servoID] < servo_target_position[servoID];

		// should we change rotation direction?
		if(servo_current_speed[servoID] != 0) {
			if((servo_current_speed[servoID]>0)!=positiveDirection) {
				// stop the movement and wait for one cycle
				servo_current_speed[servoID] = 0;
				// ESP_LOGI(LOG_TAG, "CALLBACK REDIRECT %d c=%d t=%d", servoID, servo_current_position[servoID], servo_target_position[servoID]);
				continue;
			}
		}

		// being here means the servo either does not move, or moves to the expected direction
		uint16_t absDistance = abs(servo_target_position[servoID] - servo_current_position[servoID]);
		uint16_t absSpeed = abs(servo_current_speed[servoID]);

		// Can we reach the destination within one tick?
		if(absDistance <= SERVO_SPEED_MIN) {
			servo_current_position[servoID] = servo_target_position[servoID];
			servo_current_speed[servoID] = 0;
		} else {
			// should we start decreasing the speed because approaching the destination?
			if(absDistance <= SERVO_SLOW_DOWN_DISTANCE) {
				absSpeed /=SERVO_SPEED_ACCELERATION;
				if(absSpeed<SERVO_SPEED_MIN) {
					absSpeed = SERVO_SPEED_MIN;
				}
			} else
				// destination is far. should we increase the speed to the maximum
				if(absSpeed < SERVO_SPEED_MAX) {
					if(absSpeed == 0) {
						// if we were at zero speed - set a minimum speed
						absSpeed = SERVO_SPEED_MIN;
					} else {
						// if we were moving already - double the speed
						absSpeed*=SERVO_SPEED_ACCELERATION;
					}
				}
			servo_current_speed[servoID] = positiveDirection? absSpeed : -absSpeed;
			servo_current_position[servoID] += servo_current_speed[servoID];
		}

		PWMBoardController::setPWM(SERVO_PWM_PORTS[servoID], 0, servo_current_position[servoID]);
	}
}

#ifdef SERVO_CALIBRATION_MODE
void ArmController::servoCalibration() {
	const uint8_t BUFF_SIZE = 4;
	char buffer[BUFF_SIZE+1] = "1234";
	uint8_t buffLen = 0;

	vTaskDelay(2000 / portTICK_PERIOD_MS);

	printf("Submit commands in format: SDDD, where S - servo ID (0-8) DDD - position in degree\n");

	// commands level loop
	while(1) {
		// characters reading loop
		while(1) {
			int ch;
			ch = getchar();
			if (ch == EOF) {
				// wait a bit for the characters to be available
				vTaskDelay(200 / portTICK_PERIOD_MS);
			} else
				if (ch == '\n') {
					// this is an end of line character - process the command
					buffer[buffLen] = 0;
					break;
				} else
					if ((ch >= '0') && (ch <='9')) {
						// this is a numeric character for our command
						if(buffLen < BUFF_SIZE) {
							buffer[buffLen] = ch;
							printf("%c", ch);
							buffLen++;
						} else {
							// overflow
							printf("\nToo long\n");
							buffLen = 0;
						}
					} else {
						// just ignore other characters
					}
		}
		// buffer contains some command
		if(buffLen > 0) {
			uint8_t servoID = buffer[0] - '0';
			char *end;
			uint8_t servoPosition = strtoul(&(buffer[1]), &end, 10);

			buffLen = 0;

			printf("\nSetting servo %d to position %d\n", servoID, servoPosition);
			setServo(servoID, servoPosition);
		}
	}
}

#endif

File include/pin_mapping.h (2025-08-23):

/*
 * pin_mapping.h
 *
 * This file defines which the real hardware IO pins were used for different functions.
 * They may differ to what is shown on the schematics.
 *
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
 */

#ifndef PIN_MAPPING_H_
#define PIN_MAPPING_H_

#include "driver/gpio.h"

/* ESP32 Pins */
/*============*/

// ESP32 pins used to control the sound module (WTV020M01)
#define PIN_ESP32_SOUND_P04_CLK GPIO_NUM_13
#define PIN_ESP32_SOUND_P05_DI GPIO_NUM_26
#define PIN_ESP32_SOUND_RESET GPIO_NUM_4

// pins used for I2C connection to the PWM multiplexing board
#define PIN_ESP32_PWM_SCL GPIO_NUM_27
#define PIN_ESP32_PWM_SDA GPIO_NUM_14

// pin used to connect to the RC receiver port
#define PIN_ESP32_RC_RX GPIO_NUM_25

// bottom RGB LED controlling pins
#define PIN_ESP32_RGB_LEFT GPIO_NUM_32
#define PIN_ESP32_RGB_RIGHT GPIO_NUM_33

// ulstrasonic distance sensor pins
#define PIN_ESP32_US_TRIG GPIO_NUM_22
#define PIN_ESP32_US_ECHO GPIO_NUM_35

// Infrared obstacle detectors pins
#define PIN_ESP32_IR_FL GPIO_NUM_18
#define PIN_ESP32_IR_FR GPIO_NUM_5
#define PIN_ESP32_IR_DL GPIO_NUM_19
#define PIN_ESP32_IR_DR GPIO_NUM_17


/* PWM Multiplexer pins (PCA9685 board) */
/*======================================*/
#define PIN_PWM_ARM_SERVO0 7
#define PIN_PWM_ARM_SERVO1 8
#define PIN_PWM_ARM_SERVO2 9
#define PIN_PWM_ARM_SERVO3 10
#define PIN_PWM_ARM_SERVO4 12
#define PIN_PWM_ARM_SERVO5 13

#define PIN_PWM_LIGHTS_HEAD 14
#define PIN_PWM_LIGHTS_REAR 11

#define PIN_PWM_US_SERVO 0

#define PIN_PWM_MOTOR_ENA 3
#define PIN_PWM_MOTOR_IN1 2
#define PIN_PWM_MOTOR_IN2 1
#define PIN_PWM_MOTOR_IN3 6
#define PIN_PWM_MOTOR_IN4 5
#define PIN_PWM_MOTOR_ENB 4

#endif /* PIN_MAPPING_H_ */

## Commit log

2019-09-15 Fresh project template
    [RoboTank-ESP32.kicad_pcb, RoboTank-ESP32.sch]
2019-09-21 More work on schematics
    [RoboTank-ESP32.sch]
2020-01-01 Schematics finalized
    [RoboTank-ESP32.sch]
2020-02-29 The hello world dance - the first launch of the motors
2020-03-15 Drafts: web Server OTA, sound module, RC module
    [RoboTank-ESP32.sch]
2020-03-21 Fixed bugs in WiFi code and sound module schematics.
    [RoboTank-ESP32.sch]
2020-03-26 Sound module fixed. Now it works.
    [RoboTank-ESP32.cpp, SoundModuleController.cpp]
2020-04-04 Arm controller with Servo Calibration shell mode.
2020-05-16 Arm servos calibrated
2020-07-31 Quick and dirty RC implemented for the motors and arm.
2020-12-26 Major update with the recent progress
    Added 3D models of the components used for the final assembly.
    Added module for controlling the lights (head, rear, RGB).
    Implemented simple RC code - robot moves and rotates the arm.
    [antenna_cradle.FCStd, sensors_console.3mf, sensors_console.FCStd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]
2021-02-28 Final modules set created. RC functionality defined.
    [voltmeter_cradle.FCStd, voltmeter_cradle.stl]
2021-04-11 Ultrasonic sensor code finalized
2025-08-23 Project ported to Visual Studio Code. Modules upgraded to the recent esp-idf.
    [BatHolder.3mf, BatHolder.FCStd, BeeperHolder.3mf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]
2026-06-21 Moved to pioarduino. Minor code adjustments.
    [FPVCameraHolder.3mf, FPVCameraHolder.FCStd]
2026-07-23 Refactoring and numerous bugfixes.
    [AITask.cpp, ArmController.cpp, LEDRMT.cpp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]

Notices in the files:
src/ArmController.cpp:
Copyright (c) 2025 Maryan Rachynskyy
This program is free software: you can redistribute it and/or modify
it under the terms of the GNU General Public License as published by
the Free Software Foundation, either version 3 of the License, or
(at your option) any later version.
